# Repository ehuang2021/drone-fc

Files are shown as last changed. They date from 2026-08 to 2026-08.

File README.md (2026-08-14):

# Custom nRF52832 Drone Flight Controller

The controller performs 500 Hz interrupt-driven IMU reads and atittude estimation, a 250 Hz PID control pipeline, drives ESC through hardware PWM, monitors a 2S LiPo battery through the ADC, and exposes system telementry and PID configurations over BLE, allowing for real-time PID tuning.
It's currently only for 1 axis, but will be scaled up for 3d space. 

## Key Structure/Features

### Firmware
- Zephyr RTOS with dedicated IMU, attitude-estimation, PID, PWM, safety, system-monitoring, and BLE threads
- GPIO interrupt and semaphore-driven MPU6050 acquisition at 500 Hz
- Non-blocking message queues between processing stages

### Attitude Estimation + Control
- Madgwick IMU filter using accelerometer and gyroscope data
- Quaternion-to-Euler conversion for roll, pitch, and yaw
- 250 Hz single-axis PID control loop
- ESC command generation through the nRF52 hardware PWM peripheral

### BLE Telemetry
- Custom BLE GATT service
- 20 Hz telemetry broadcasts with attitude, throttle, battery voltage, and uptime
- Writable BLE characteristic for runtime PID gain configuration

### System Monitoring
- ADC-based monitoring of a 2S LiPo battery through a voltage divider
- Moving-average voltage filtering
- Approximate battery SOC tracking
- Safety thread with heartbeat monitoring, roll-limit fault detection, and hardware watchdog support

## Architecture Overview
```mermaid
flowchart LR
    MPU["MPU6050<br/>500 Hz DRDY"] -->|GPIO interrupt| SEM["Semaphore"]
    SEM --> IMU["IMU Thread<br/>500 Hz<br/>I²C acquisition"]
    IMU -->|k_msgq| ATT["Attitude Thread<br/>500 Hz<br/>Madgwick Filter"]
    ATT -->|Downsample 2:1<br/>k_msgq| PID["PID Thread<br/>250 Hz"]
    PID -->|k_msgq| PWM["PWM Thread<br/>ESC command"]
    PWM --> ESC["ESC / Motor<br/>50 Hz PWM"]

    IMU -. heartbeat .-> SAFETY["Safety Thread<br/>watchdog / fault monitoring"]
    ATT -. heartbeat / roll .-> SAFETY
    PID -. heartbeat .-> SAFETY
    SAFETY -. flight state .-> PWM

    ATT -. attitude .-> BLE["BLE Telemetry Thread<br/>20 Hz notifications"]
    PID -. PID output .-> BLE
    PWM -. throttle .-> BLE

    ADC["2S LiPo<br/>ADC Monitor<br/>5 Hz"] -. voltage .-> BLE

    PHONE["nRF Connect / BLE Client"] -->|Write Kp, Ki, Kd| BLE
    BLE -->|PID command queue| PID
```

## Schematic
The custom PCB integrates the nRF52832 flight controller, MPU6050
interface, 2S LiPo voltage monitoring, ESC interface, 5 V-to-3.3 V
regulation, and SWD programming/debug access.

Flight controller schematic

[View full schematic PDF](hardware/drone_fc_v1.0.pdf)

### PCB
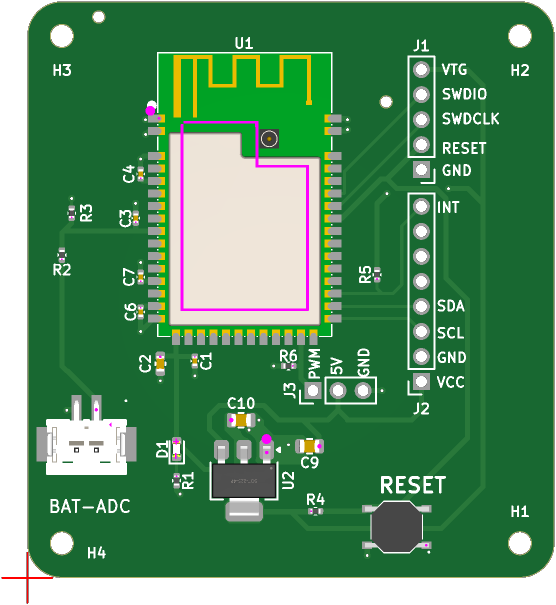
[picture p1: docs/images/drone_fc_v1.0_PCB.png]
Flight Controller PCB


## Future Additions:
- Three axis flight (which would probably mean a kalman filter over the current madgwick, with a gps module AND a nested PID loop)

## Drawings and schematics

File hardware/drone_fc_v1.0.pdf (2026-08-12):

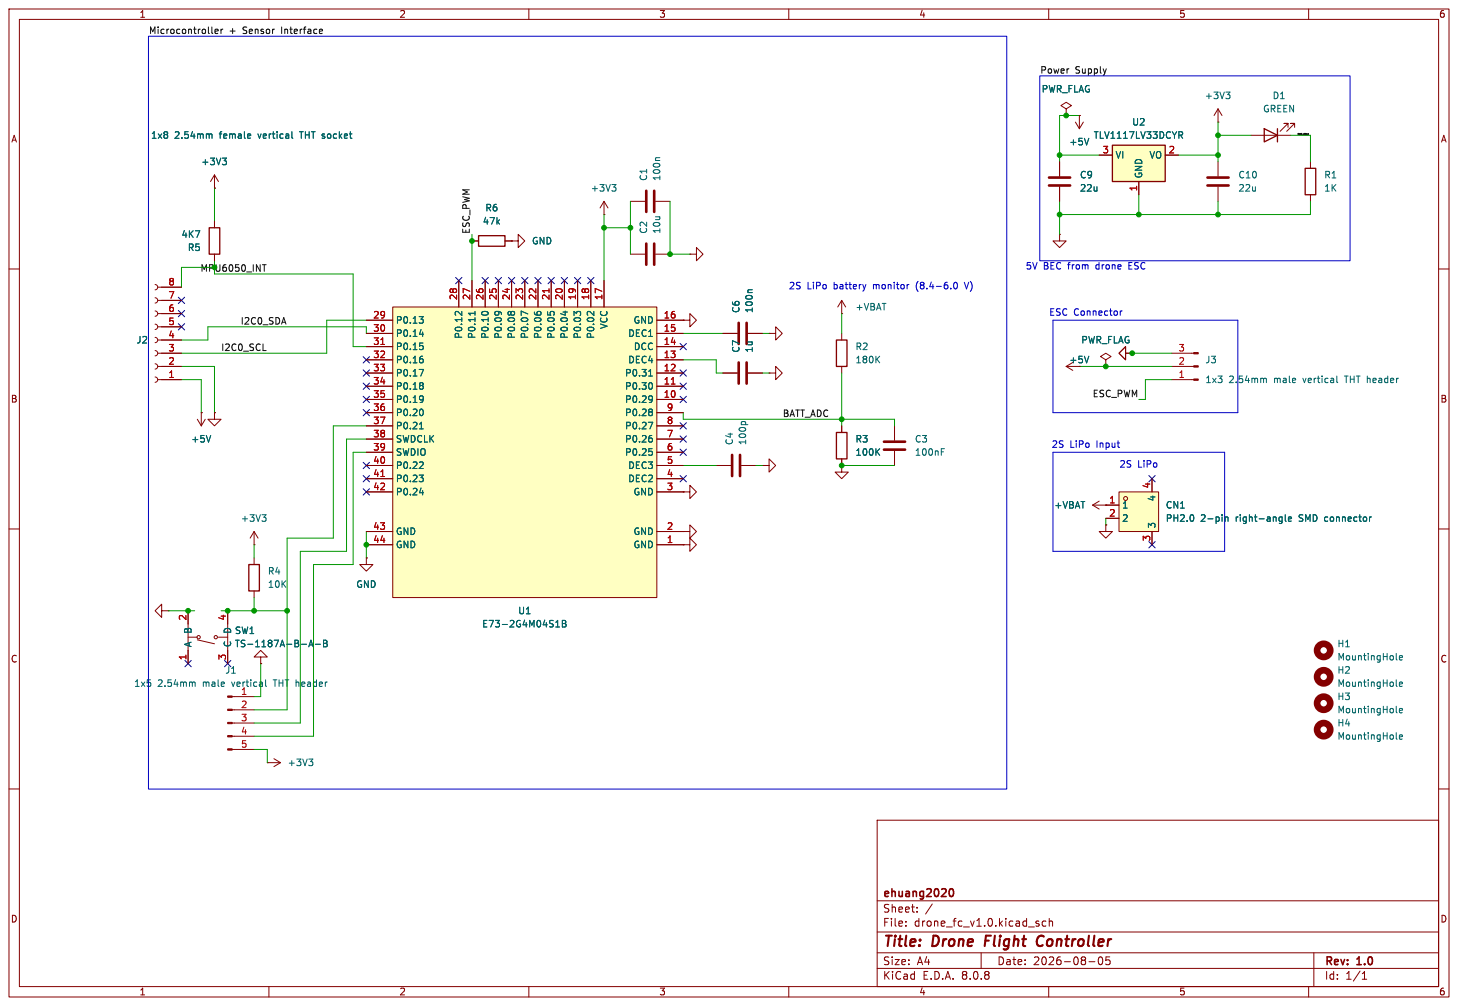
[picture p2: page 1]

4 SW1 TS-1187A-B-A-B GND 1 P0.29 10 P0.30 11 P0.31 12 DEC4 13 DCC 14 DEC1 15 GND 16 VCC 17 P0.02 18 P0.03 19 GND 2 P0.04 20 P0.05 21 P0.06 22 P0.07 23 P0.08 24 P0.09 25 P0.10 26 P0.11 27 P0.12 28 P0.13 29 GND 3 P0.14 30 P0.15 31 P0.16 32 P0.17 33 P0.18 34 P0.19 35 P0.20 36 P0.21 37 SWDCLK 38 SWDIO 39 DEC2 4 P0.22 40 P0.23 41 P0.24 42 GND 43 GND 44 DEC3 5 P0.25 6 P0.26 7 P0.27 8 P0.28 9 U1 E73-2G4M04S1B

Id: 1/1 Title: Drone Flight Controller File: drone_fc_v1.0.kicad_sch Sheet: / ehuang2020 R3

4 CN1 PH2.0 2-pin right-angle SMD connector H1 MountingHole H3 MountingHole H2 MountingHole H4 MountingHole

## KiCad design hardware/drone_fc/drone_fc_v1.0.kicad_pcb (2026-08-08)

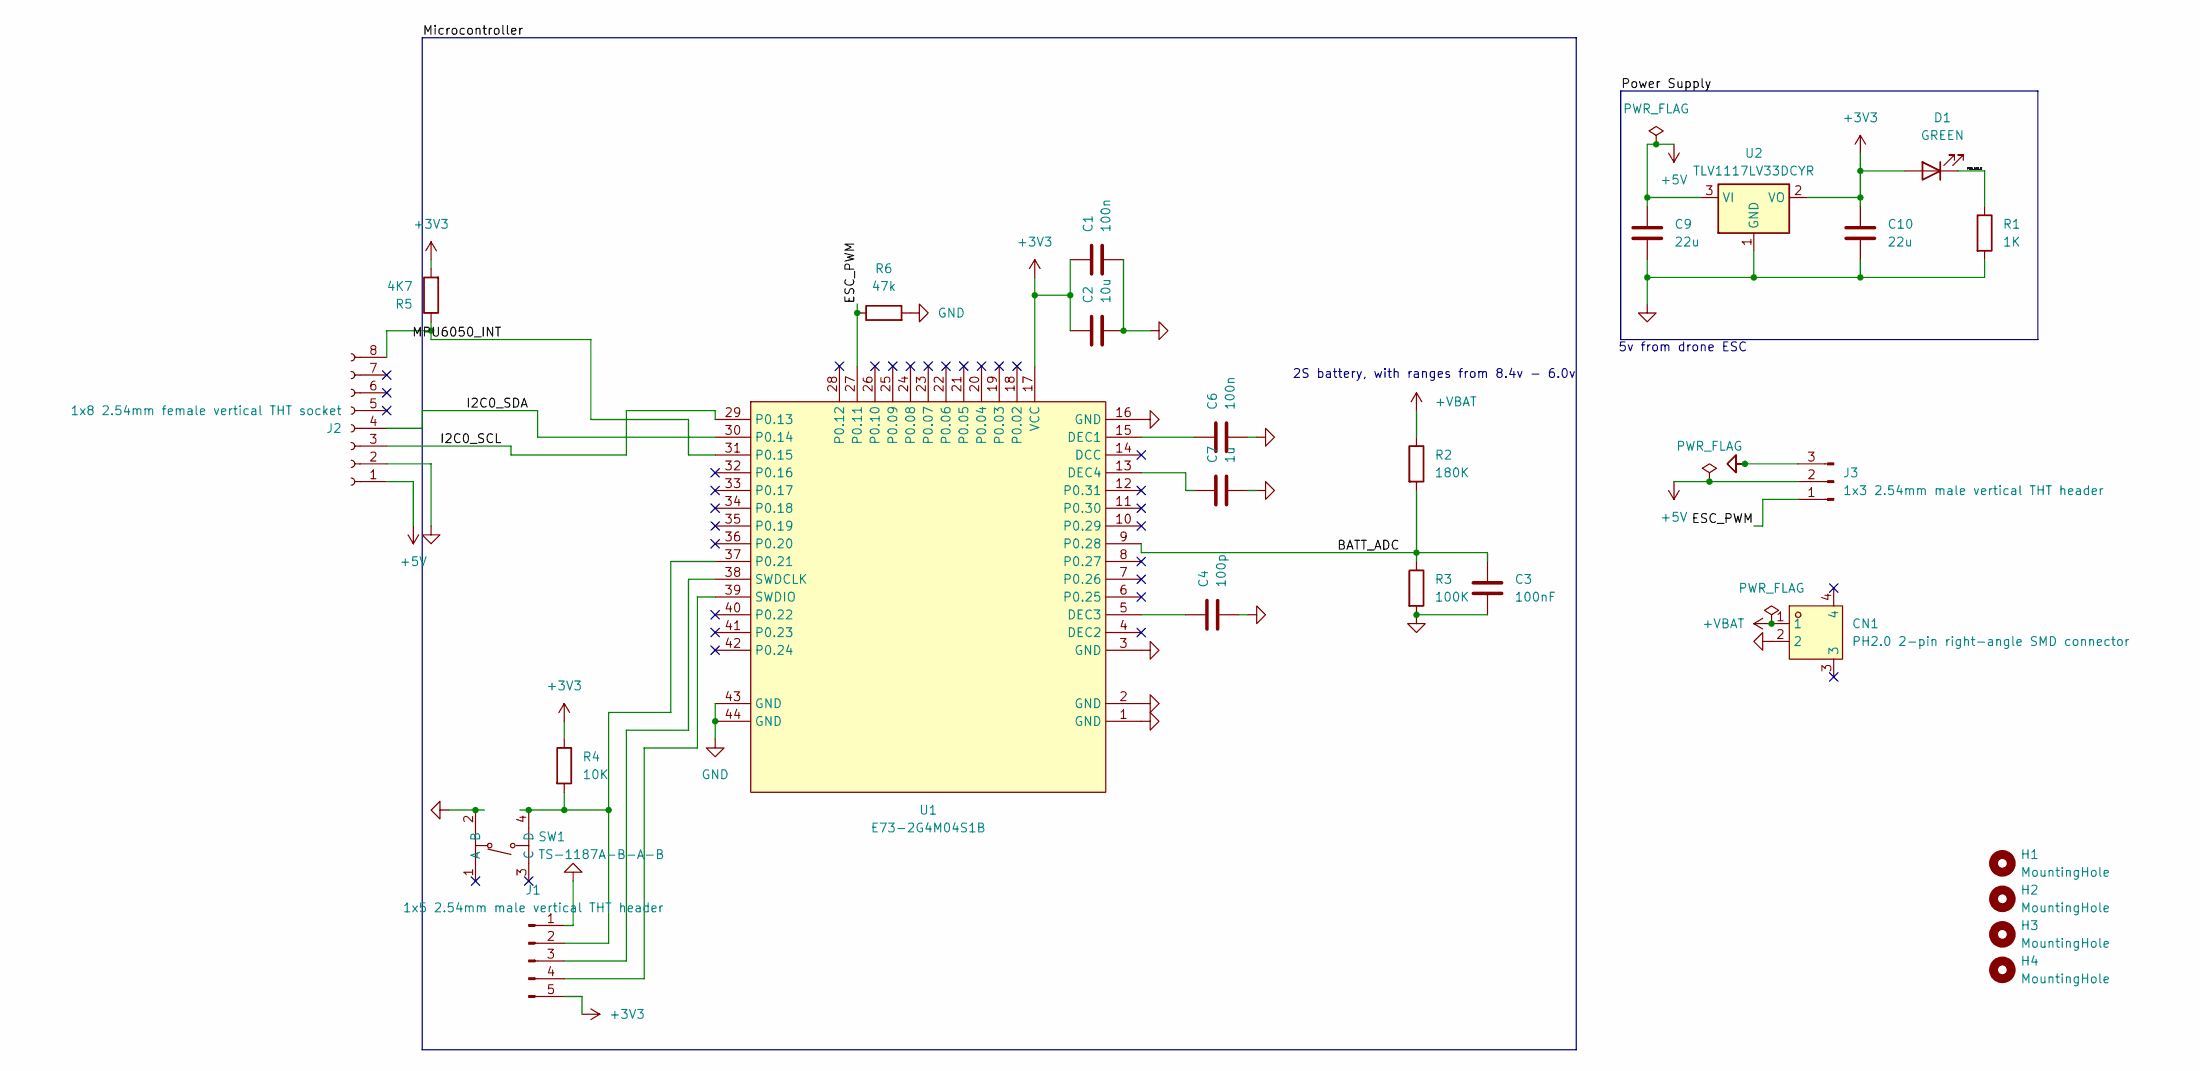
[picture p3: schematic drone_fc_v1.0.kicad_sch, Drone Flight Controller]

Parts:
C1, C6: 100n; C_0402_1005Metric; MPN CL05B104KB54PNC; LCSC Part C307331
C2: 10u; C_0603_1608Metric; MPN CL10A106KP8NNNC; LCSC Part C19702
C3: 100nF; C_0402_1005Metric; MPN CL05B104KB54PNC; LCSC Part C307331
C4: 100p; C_0402_1005Metric; MPN 0402CG101J500NT; LCSC Part C1546
C7: 1u; C_0402_1005Metric; MPN CL05A105KA5NQNC; LCSC Part C52923
C9, C10: 22u; C_0805_2012Metric; MPN C2012X5R1A226MT0J0E; LCSC Part C361180
CN1: PH2.0 2-pin right-angle SMD connector; CONN-SMD_PH2.0-1X2PW; MPN PH2.0-2P-LT; LCSC Part C722761
D1: GREEN; LED_0603_1608Metric; MPN SML-D13FWT86; LCSC Part C5372156
H1, H2, H3, H4: MountingHole; MountingHole_2.2mm_M2
J1: 1x5 2.54mm male vertical THT header; PinHeader_1x05_P2.54mm_Vertical; MPN CS-1109-1X5(L11.5)PA6T; LCSC Part C18213720
J2: 1x8 2.54mm female vertical THT socket; PinSocket_1x08_P2.54mm_Vertical; MPN 2.54-1*8P母环保; LCSC Part C27438
J3: 1x3 2.54mm male vertical THT header; PinHeader_1x03_P2.54mm_Vertical; MPN PZ2.54-1X3P-H25; LCSC Part C42431683
R1: 1K; R_0402_1005Metric; MPN 0402WGF1001TCE; LCSC Part C11702
R2: 180K; R_0402_1005Metric; MPN RC-02K1803FT; LCSC Part C324831
R3: 100K; R_0402_1005Metric; MPN 0402WGF1003TCE; LCSC Part C25741
R4: 10K; R_0402_1005Metric; MPN 0402WGF1002TCE; LCSC Part C25744
R5: 4K7; R_0402_1005Metric; MPN 0402WGF4701TCE; LCSC Part C25900
R6: 47k; R_0402_1005Metric
SW1: TS-1187A-B-A-B; SW-SMD_4P-L5.1-W5.1-P3.70-LS6.5-TL_H1.5; MPN TS-1187A-B-A-B; LCSC Part C318884
U1: E73-2G4M04S1B; WIRELM-SMD_E73-2G4M04S1B; MPN E73-2G4M04S1B; LCSC Part C411306
U2: TLV1117LV33DCYR; SOT-223-3_TabPin2; MPN TLV1117LV33DCYR; LCSC Part C15578

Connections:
+3V3: C1.1, C2.1, C10.1, D1.2 (A), J1.5, R4.1, R5.2, U1.17 (VCC), U2.2 (VO)
+5V: C9.1, J2.1, J3.2, U2.3 (VI)
+VBAT: CN1.1, R2.1
/BATT_ADC: C3.1, R2.2, R3.1, U1.9 (P0.28)
/ESC_PWM: J3.1, R6.1, U1.27 (P0.11)
/I2C0_SCL: J2.3, U1.29 (P0.13)
/I2C0_SDA: J2.4, U1.30 (P0.14)
/MPU6050_INT: J2.8, R5.1, U1.31 (P0.15)
/PWR_LED_K: D1.1 (K), R1.1
GND: C1.2, C2.2, C3.2, C4.2, C6.2, C7.2, C9.2, C10.2, CN1.2, J1.1, J2.2, J3.3, R1.2, R3.2, R6.2, SW1.2 (B), U1.1 (GND), U1.2 (GND), U1.3 (GND), U1.16 (GND), U1.43 (GND), U1.44 (GND), U2.1 (GND)
unnamed: J1.2, R4.2, SW1.4 (D), U1.37 (P0.21)
unnamed: J1.3, U1.38 (SWDCLK)
unnamed: J1.4, U1.39 (SWDIO)
unnamed: C6.1, U1.15 (DEC1)
unnamed: C4.1, U1.5 (DEC3)
unnamed: C7.1, U1.13 (DEC4)

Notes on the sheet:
2S battery, with ranges from 8.4v - 6.0v
5v from drone ESC

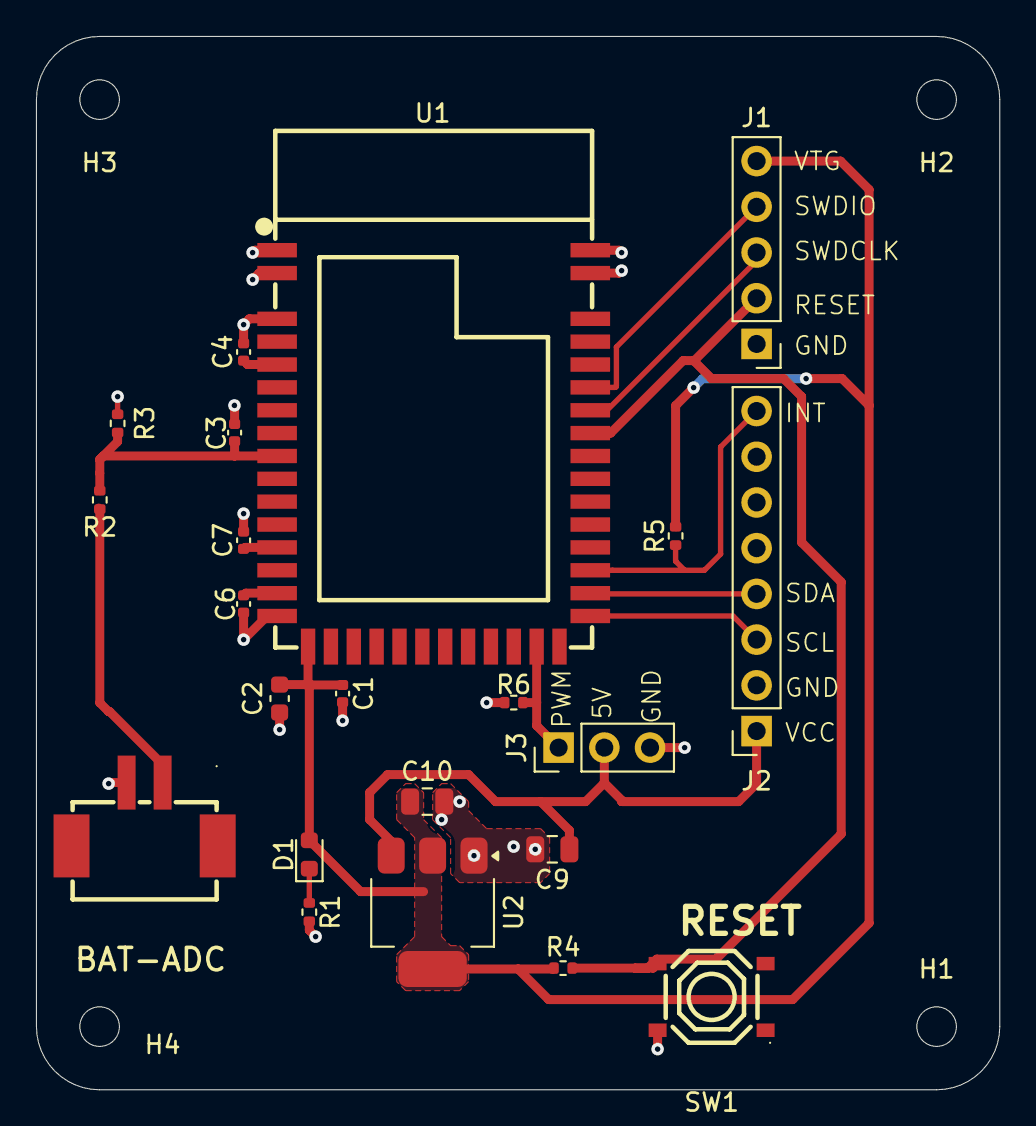
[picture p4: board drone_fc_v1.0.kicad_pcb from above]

Board: 2 copper layers, 53.5 x 58.5 mm, 26 parts (0 on the bottom side), 16 nets.

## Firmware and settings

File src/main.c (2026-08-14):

#include <zephyr/kernel.h>
#include <zephyr/drivers/i2c.h>
#include <zephyr/drivers/gpio.h>
#include <zephyr/logging/log.h>
#include <zephyr/drivers/pwm.h>


#include "mpu6050.h"
#include "global_objects.h"
#include "imu.h"
#include "ble.h"
#include "safety.h"

#define I2C_NODE DT_NODELABEL(mpu6050)
#define ESC_PWM_NODE DT_NODELABEL(pwm1)


// Thread Definitions
#define SAFETY_STACKSIZE 1024
#define SAFETY_THREAD_PRIORITY 0

#define IMU_STACKSIZE 1024
#define IMU_THREAD_PRIORITY 1

#define ATTITUDE_STACKSIZE 2048
#define ATTITUDE_THREAD_PRIORITY 2

#define PID_STACKSIZE 1024
#define PID_THREAD_PRIORITY 3

#define PWM_STACKSIZE 1024
#define PWM_THREAD_PRIORITY 4

#define DRONE_SYSTEMS_STACKSIZE 1024
#define DRONE_SYSTEMS_THREAD_PRIORITY 5

#define BLE_STACKSIZE 2048
#define BLE_THREAD_PRIORITY 6

// Initalize GPIO
static struct gpio_dt_spec mpu_int_gpio = GPIO_DT_SPEC_GET(I2C_NODE, int_gpios);
static struct gpio_callback mpu_int_cb_data;

static const struct device *esc_pwm = DEVICE_DT_GET(ESC_PWM_NODE);

LOG_MODULE_REGISTER(main_task, LOG_LEVEL_DBG);


// This function init's the imu inturupt, which is responsible for thread unblocking for imu.c
int initalize_imu_inturrupts() {
    int ret = gpio_pin_configure_dt(&mpu_int_gpio, GPIO_INPUT);
    if (ret) {
            LOG_ERR("gpio_pin_configure_dt Error code: %d", ret);
            return ret;
    }

    ret = gpio_pin_interrupt_configure_dt(&mpu_int_gpio, GPIO_INT_EDGE_TO_ACTIVE);
    if (ret) {
            LOG_ERR("gpio_pin_interrupt_configure_dt error: Error code: %d", ret);
            return ret;
    }
    gpio_init_callback(&mpu_int_cb_data, mpu_inturrupt, BIT(mpu_int_gpio.pin)); 	
    gpio_add_callback(mpu_int_gpio.port, &mpu_int_cb_data);

    return 0;


}

// Initalizes the imu -> attitude message queue
K_MSGQ_DEFINE(attitude_message_queue, sizeof(struct imu_packet), 1, sizeof(void *));
// Initlaize the attiude -> pid thread
K_MSGQ_DEFINE(controls_message_queue, sizeof(attitude_data), 1, sizeof(void *));
// initlaize pid -> pwm thread
K_MSGQ_DEFINE(pwm_message_queue, sizeof(float), 1, sizeof(void *));


K_THREAD_DEFINE(imu_tasks, IMU_STACKSIZE, mpu_thread, NULL, NULL, NULL, IMU_THREAD_PRIORITY, 0, 0);
K_THREAD_DEFINE(attitude_tasks, ATTITUDE_STACKSIZE, attitude_thread, NULL, NULL, NULL, ATTITUDE_THREAD_PRIORITY, 0, 0);
K_THREAD_DEFINE(pid_tasks, PID_STACKSIZE, pid_thread, NULL, NULL, NULL, PID_THREAD_PRIORITY, 0, 0);
K_THREAD_DEFINE(pwm_tasks, PWM_STACKSIZE, pwm_thread, NULL, NULL, NULL, PWM_THREAD_PRIORITY, 0, 0);
K_THREAD_DEFINE(drone_systems_tasks, DRONE_SYSTEMS_STACKSIZE, drone_systems_thread, NULL, NULL, NULL, DRONE_SYSTEMS_THREAD_PRIORITY, 0, 0);
K_THREAD_DEFINE(ble_tasks, BLE_STACKSIZE, ble_thread, NULL, NULL, NULL, BLE_THREAD_PRIORITY, 0, 0);
K_THREAD_DEFINE(safety_tasks, BLE_STACKSIZE, ble_thread, NULL, NULL, NULL, SAFETY_THREAD_PRIORITY, 0, 0);




int main() {


    int ret = ble_init();
    if (ret) {
        LOG_ERR("BLE init failed, continuing without BLE");
    }

    init_mpu6050();
    initalize_imu_inturrupts();



    if (!device_is_ready(esc_pwm)) {
        LOG_ERR("PWM device not ready");
        return -1;
    }

    pwm_set(esc_pwm, 0, PWM_MSEC(20), PWM_USEC(1000), PWM_POLARITY_NORMAL);

    init_watchdog();

    return 0;
}

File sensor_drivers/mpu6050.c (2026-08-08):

#include <zephyr/kernel.h>
#include <zephyr/drivers/i2c.h>
#include <zephyr/logging/log.h>
#include "mpu6050.h"

/*The outputs here will return the acceleration*/
// Accelerometer Measurements
#define ACCEL_XOUT_7_0  0x3B
// Gyroscope Measurements
#define GYRO_XOUT_7_0 0x43
#define PWR_MGMT_1 0x6B
#define GYRO_CONFIG 0x1B
#define CONFIGURATION 0x1A
#define SAMPLE_RATE_DIVIDER 0x19
#define INT_PIN_CONFIG 0x37
#define INT_ENABLE 0x38

#define I2C_NODE DT_NODELABEL(mpu6050)

// GYRO Deadzone Fix
#define GYRO_DZ 25
#define LSB_SENS 16384


LOG_MODULE_REGISTER(mpu6050_driver, LOG_LEVEL_DBG);

static int16_t accel_bias_x = 0;
static int16_t accel_bias_y = 0;
static int16_t accel_bias_z = 0;
static int16_t gyro_bias_x = 0;
static int16_t gyro_bias_y = 0;
static int16_t gyro_bias_z = 0;

static const struct i2c_dt_spec dev_i2c = I2C_DT_SPEC_GET(I2C_NODE);


int read_data(struct imu_data *data) {

    uint8_t vals[14];
    // Read x,y,z vals at once
    int ret = i2c_burst_read_dt(&dev_i2c, ACCEL_XOUT_7_0, vals, 14);
    if (ret != 0) {
        LOG_ERR("read_data issue. Error code: %d", ret);
        return ret;
    }

    data->ax = (vals[0] << 8 | vals[1]) + accel_bias_x;
    data->ay = (vals[2] << 8 | vals[3]) + accel_bias_y;
    data->az = (vals[4] << 8 | vals[5]) + accel_bias_z;
    data->temp = (vals[6] << 8 | vals[7]);
    data->gx = (vals[8] << 8 | vals[9]) - gyro_bias_x;
    data->gy = (vals[10] << 8 | vals[11]) - gyro_bias_y;
    data->gz = (vals[12] << 8 | vals[13]) - gyro_bias_z;


    return 0;

}



int init_mpu6050() {
    
    float accel_sum_x = 0, accel_sum_y = 0, accel_sum_z = 0, gyro_sum_x = 0, gyro_sum_y = 0, gyro_sum_z = 0;
    struct imu_data acc;

    // Check I2C bus
    if (!device_is_ready(dev_i2c.bus)) {
        return -1;
    }

    // Start-up register config to Sensor
    uint8_t write_buf1[] = {PWR_MGMT_1, 0x00};
    int ret = i2c_write_dt(&dev_i2c, write_buf1, sizeof(write_buf1));
    if (ret != 0) {
        LOG_ERR("i2c_write write_buf1 issue. Error code: %d", ret);
        return ret;
    }

    // Configures the Gyro full scale range to 500 deg/s
    uint8_t write_buf2[] = {GYRO_CONFIG, 0b00001000};
    ret = i2c_write_dt(&dev_i2c, write_buf2, sizeof(write_buf2));
    if (ret != 0) {
        LOG_ERR("i2c_write write_buf2 issue. Error code: %d", ret);
        return ret;
    }

    // Configures the on board digital low pass filter for cutoffs of (184 hz for accelerometer, 188 hz for gyroscope, with a 2.0 ms and 1.9 ms delay respectively)
    uint8_t write_buf3[] = {CONFIGURATION, 0b0000001};
    ret = i2c_write_dt(&dev_i2c, write_buf3, sizeof(write_buf3));
    if (ret != 0) {
        LOG_ERR("i2c_write dlpf issue. Error code: %d", ret);
        return ret;
    }

    // sample rate = gyroscope output rate / (1 + div), where gyro output is 1000 hz from the low pass filter
    // Aiming for 500 hz
    uint8_t write_buf4[] = {SAMPLE_RATE_DIVIDER, 0b0000001};
    ret = i2c_write_dt(&dev_i2c, write_buf4, sizeof(write_buf4));
    if (ret != 0) {
        LOG_ERR("i2c_write sample divider issue. Error code: %d", ret);
        return ret;
    }

    // Interrupt is active-low, open-drain, emits a 50 us pulse, and clears on any read.
    // R5 provides the external pull-up to +3V3 on the flight controller.
    uint8_t write_buf5[] = {INT_PIN_CONFIG, 0b11010000};
    ret = i2c_write_dt(&dev_i2c, write_buf5, sizeof(write_buf5));
    if (ret != 0) {
        LOG_ERR("i2c_write sample divider issue. Error code: %d", ret);
        return ret;
    }

    // Inturrupt Pin enable, and sets it for data ready interrupt
    uint8_t write_buf6[] = {INT_ENABLE, 0b00000001};
    ret = i2c_write_dt(&dev_i2c, write_buf6, sizeof(write_buf6));
    if (ret != 0) {
        LOG_ERR("i2c_write sample divider issue. Error code: %d", ret);
        return ret;
    }


    int num = 1000;
    // Perform a baseline calibration of the sensor. 
    for (int i = 0; i < num; i++) {
        read_data(&acc);
        accel_sum_x += acc.ax;
        accel_sum_y += acc.ay;
        accel_sum_z += acc.az;
        gyro_sum_x += acc.gx;
        gyro_sum_y += acc.gy;
        gyro_sum_z += acc.gz;

    }
    accel_bias_x = 0-accel_sum_x/num;
    accel_bias_y = 0-accel_sum_y/num;
    accel_bias_z = 16384-accel_sum_z/num;

    gyro_bias_x = gyro_sum_x/num;
    gyro_bias_y = gyro_sum_y/num;
    gyro_bias_z = gyro_sum_z/num;
    LOG_INF("Accel Bias: %d, %d, %d\nGyro Bias: %d, %d, %d", accel_bias_x, accel_bias_y, accel_bias_z, gyro_bias_x, gyro_bias_y, gyro_bias_z);





    return 0;


}

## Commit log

2026-06-04 Initial commit, mpu6050 driver
2026-06-04 fixed init_sensor logic with i2c passings
    [mpu6050.c]
2026-06-04 added calibration during init and gyro setup
2026-06-07 Added initalize imu inturrupts
2026-06-07 renamed the imu struct variables since typing is too hard
2026-06-07 Added the semaphore and inturrupt logic, as well as all of the thread logic of passing data through minus the message queue
2026-06-07 Linked imu.h
2026-06-08 Added the imu thread to main
2026-06-08 added inturrupt configurations for sensor
2026-06-08 Finished IMU thread, aongisde the message pipeline to the altitude thread
2026-06-09 Refactored the filter to signal precision floats and replaced 64 bit double math to 32 bit to run on the nRF62832 FPU
2026-06-09 Added attiude and magdwick filter files
2026-06-09 First commit for the attitude thread, at first glance it works
2026-06-09 Changed the packet structure to the attitude thread to push float values for accel and gyro instead of uint16_t
2026-06-09 added attitude thread
2026-06-10 Started PCB layouts
    [drone_fc_v1.0.kicad_pcb, drone_fc_v1.0.kicad_sch]
2026-06-10 chore: updated .gitignore to include KiCad files
2026-06-11 Fixed GYRO_LSB_SENS multiplier
2026-06-11 fix: SEq_n (Quanterion) values were changed to q->n values, now the filter no longer gets stuck
2026-06-11 update: changed debug messages from fixing madgwick filter. This thread should be working now.
2026-06-11 feat: initial schematic design
    Completed the base schematic for the project. Major hardware blocks include:
    - nRF52832 core setup (configured for internal LDO, 32MHz crystal only)
    - 5V to 3.3V linear regulator for ESC power input
    - 2S battery voltage divider (180k/100k) mapped to AIN
    - MPU6050 IMU on I2C0 with active-low interrupt and external pull-up
    - Hardware reset button with 10k pull-up resistor
    [drone_fc_v1.0.kicad_sch]
2026-06-12 feat: Finished schematics, and most of the footprinting
    [drone_fc_v1.0.kicad_sch]
2026-08-08 Added pid, pwm threads
    [drone_fc_v1.0.kicad_pcb, drone_fc_v1.0.kicad_sch]
2026-08-12 added ADC and BLE threads
2026-08-12 added bluetooth thread, and polished readme
    [drone_fc_v1.0.kicad_sch]
2026-08-14 Added safety thread
2026-08-14 Updated README for safety thread inclusion
2026-08-14 Correct Madgwick filter spelling
